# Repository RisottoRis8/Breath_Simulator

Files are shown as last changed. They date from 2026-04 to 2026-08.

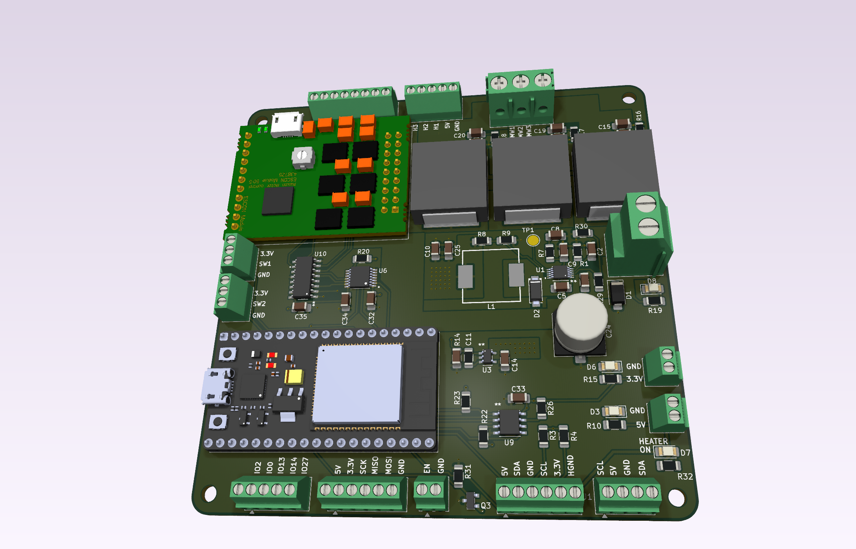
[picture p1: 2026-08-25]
hardware/documentation/others/motherboard_rev2.png

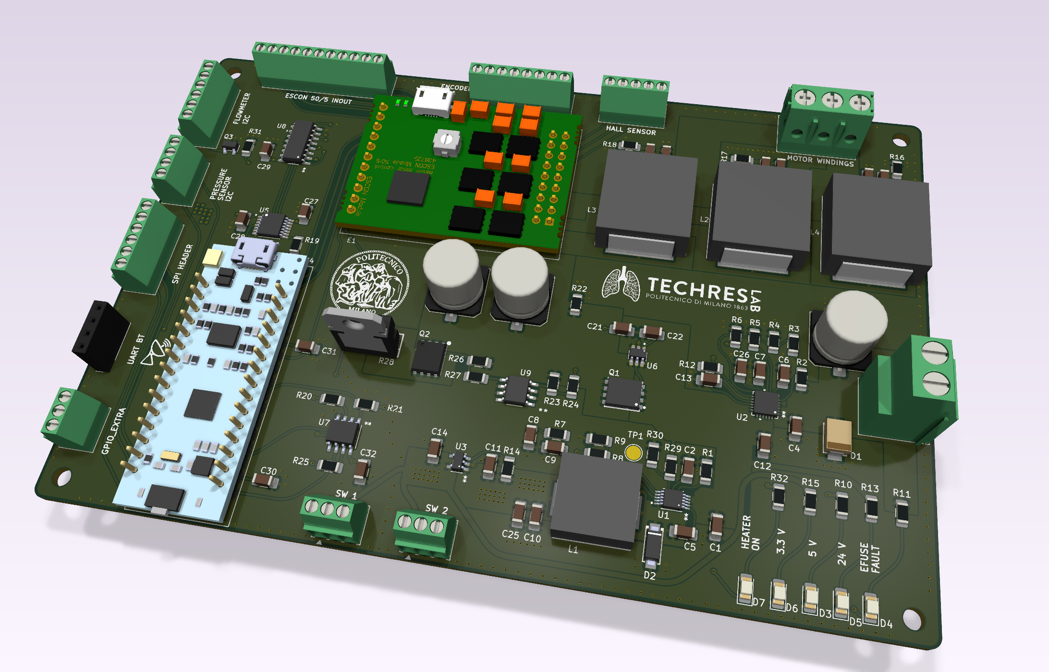
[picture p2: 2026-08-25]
hardware/documentation/others/motherboard.png

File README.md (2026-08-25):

# Syringe-Based Breathing Simulator

University biomedical engineering project developed by Gruppo Viola: a motorized syringe generates controlled air flow at its outlet. The system combines a BLDC motor with an ESCON 50/5 drive, encoder feedback, Sensirion pressure or mass-flow sensing, PID control, BLE communication and a desktop monitoring GUI.

This repository presents the final ESP32-based system together with its electronics, control software, measurement data and technical documentation. Earlier firmware, interface and hardware iterations are preserved separately as supporting development history.

## System overview

The final firmware runs on an ESP32 and coordinates:

- flow sensing through SDP810 or SFM3300 devices;
- motor control through the ESCON driver;
- incremental encoder feedback and homing signals;
- PID regulation of the generated flow;
- external SPI EEPROM storage;
- HM-10 compatible BLE telemetry and commands.

The final architecture is supported by a custom control board and a desktop BLE interface. Earlier STM32 and ESP32 bridge implementations are preserved as development iterations.

## Repository map

| Area | Contents |
| --- | --- |
| [docs](docs/) | Report, architecture notes, protocol notes and project catalog |
| [firmware](firmware/) | ESP32 and STM32 firmware area |
| [software/gui](software/gui/) | Main desktop control interface, [main_gui.py](software/gui/main_gui.py) |
| [software/tools](software/tools/) | BLE terminal, CSV visualizer and Python dependency notes |
| [hardware](hardware/) | KiCad boards, custom libraries and board documentation |
| [analysis/matlab](analysis/matlab/) | Measurement interpolation and resistance-analysis scripts |
| [data/measurements/raw](data/measurements/raw/) | Original experimental CSV measurements |
| [mechanical/renders](mechanical/renders/) | Syringe assembly render |
| [archive](archive/) | GUI prototypes and duplicate/legacy experiments |
| [docs/references/datasheets](docs/references/datasheets/) | Component reference documents |
| [archive/sensor-sdp800](archive/sensor-sdp800/) | Sensor sample-code project and documentation |

The detailed working inventory is in [docs/PROJECT_CATALOG.md](docs/PROJECT_CATALOG.md).

## Final system

- **Controller:** [firmware/esp32/main](firmware/esp32/main) coordinates sensing, encoder feedback, motor actuation, PID flow regulation, EEPROM storage and BLE communication.
- **Control interface:** [software/gui/main_gui.py](software/gui/main_gui.py) provides BLE discovery, connection management, real-time flow/position/PWM plots, operating modes, calibration controls, logging and emergency stop.
- **Electronics:** [hardware/motherboard-r2](hardware/motherboard-r2) and [hardware/pogo-adapter](hardware/pogo-adapter) contain the KiCad designs for the control board and sensor adapter. The original motherboard design is preserved as [motherboard-r1](hardware/motherboard-r1).
- **Validation data:** [data/measurements/raw](data/measurements/raw/) contains the experimental acquisitions used during characterization and analysis.

## Communication status

The final ESP32 interface uses an HM-10-compatible BLE service (`FFE0/FFE1`) and telemetry frames in the form `SNSR <flow> <encoder_position> <pwm>`. The communication details are summarized in [docs/protocol.md](docs/protocol.md).

The earlier Nordic UART bridge and STM32 variants remain available in [archive](archive/) as development iterations and are not part of the primary ESP32 control path.

## Running the Python tools

The main GUI requires Python packages including PyQt6, pyqtgraph, bleak and qasync. The BLE terminal declares its dependency in [requirements-ble.txt](software/tools/requirements-ble.txt).

The CSV visualizer is a separate Streamlit utility:

```text
streamlit run software/tools/visualizer.py
```

Its expected columns are `Timestamp_s` and `Pressione_Pa`; the raw measurements commonly use `Time_s` and `Pressure_Pa`, so they are not directly interchangeable yet.

## Firmware and hardware

The Arduino ESP32 sketch is located in [firmware/esp32/main](firmware/esp32/main) and uses the local NimBLE-Arduino library in [firmware/esp32/libraries](firmware/esp32/libraries).

KiCad source files are separated from local state, backups and manufacturing exports. The root [.gitignore](.gitignore) excludes regenerable artifacts while keeping source schematics, PCB files, custom libraries and experimental measurements available for review.

## Project documentation

- [Project catalog](docs/PROJECT_CATALOG.md)
- [Communication protocol notes](docs/protocol.md)
- [Project report](docs/report_biomed.pdf)
- [Code-flow diagram](docs/architecture/code-flow-diagram.drawio)
- [Firmware pseudocode](docs/architecture/codice.pseudo)
- [Assembly render](mechanical/renders/syringe-assembly.jpg)

## Development history

Previous ESP32 sketches, STM32 firmware, BLE bridges and GUI prototypes are preserved in [archive](archive/). They document the iterations that led to the final ESP32 architecture, while the project entrypoints above describe the system delivered by the team.

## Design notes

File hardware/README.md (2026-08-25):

# Hardware

KiCad source projects, custom libraries and board revisions will be grouped here. Generated manufacturing output and local KiCad state are excluded by the root `.gitignore`.

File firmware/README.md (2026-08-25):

# Firmware

Firmware is being separated into ESP32 and STM32 projects. The active candidate and archived prototypes will be documented after the controller and hardware revision are confirmed.

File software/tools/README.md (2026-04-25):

# BLE Terminal

A cross-platform command-line BLE terminal program that scans for BLE devices and connects to BLE UART emulators (Nordic NUS).

## Requirements

- Python 3.8+
- bleak library

## Installation

```bash
cd PythonBLECOMM
pip install -r requirements.txt
```

## Usage

```bash
python ble_terminal.py
```

### Features

1. **Scan** - Automatically scans for 5 seconds and lists all nearby BLE devices
2. **Select** - Enter the device number to connect
3. **Connect** - Connects to the selected device using Nordic UART Service (NUS)
4. **Interactive Mode** - Type messages to send, received data is displayed automatically

### Commands in Interactive Mode

- **Type and press Enter** - Send data to BLE device
- `quit` / `exit` / `q` - Disconnect and exit
- `help` - Show help

### Nordic UART Service UUIDs

- Service: `6e400001-b5a3-f393-e0a9-e50e24d4179e`
- TX (Write): `6e400002-b5a3-f393-e0a9-e50e24d4179e`
- RX (Notify): `6e400003-b5a3-f393-e0a9-e50e24d4179e`

## Platform Notes

### macOS
- May need to grant Bluetooth permissions in System Preferences
- Works with native CoreBluetooth (handled by bleak)

### Linux
- May need to install BlueZ: `sudo apt install bluez`
- May need to run with sudo or add user to bluetooth group

### Windows
- Works natively with Windows BLE API
- May need to install Bluetooth LE Enumerator from Windows Update

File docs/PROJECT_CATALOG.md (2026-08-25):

# Project catalog

This document is the repository inventory for the project presented in the root README.

## Public project areas

| Area | Current location | Target location | Status |
| --- | --- | --- | --- |
| Project documentation | `README.md`, `docs/`, `mechanical/` | `README.md`, `docs/`, `mechanical/` | Organized |
| ESP32 main firmware | `firmware/esp32/main/` | `firmware/esp32/main/` | Final system |
| ESP32 bridges and sketches | `firmware/esp32/bridges/` | `firmware/esp32/bridges/`, `archive/` | Prototype/history |
| STM32 projects | `firmware/stm32/` | `firmware/stm32/`, `archive/` | Historical implementations |
| Python GUI | `software/gui/main_gui.py` | `software/gui/` | Final ESP32 control interface |
| Python tools | `software/tools/` | `software/tools/` | Utilities |
| KiCad boards | `hardware/motherboard-r1/`, `hardware/motherboard-r2/`, `hardware/pogo-adapter/` | `hardware/` | Preserve sources |
| KiCad custom libraries | `hardware/libraries/` | `hardware/libraries/` | Required dependency |
| MATLAB analysis | `analysis/matlab/` | `analysis/matlab/` | Analysis source |
| Measurements | `data/measurements/raw/` | `data/measurements/raw/` | Experimental data |
| Datasheets and sensor examples | `docs/references/datasheets/`, `archive/sensor-sdp800/` | `docs/references/`, `archive/` | Review licenses and relevance |

## Verified technical facts

- `firmware/esp32/main/` is the final ESP32 firmware implementation.
- `software/gui/main_gui.py` is the main desktop interface for the ESP32 HM-10 service and `SNSR` telemetry.
- The repository contains both a direct ESP32 architecture and an older STM32 plus ESP32 bridge architecture.
- BLE identifiers, command syntax, telemetry frames and UART baud rates are not uniform across the repository.
- Both `hardware/motherboard-r1/` and `hardware/motherboard-r2/` contain complete KiCad source sets; `motherboard-r2` is the primary board design.
- Measurement CSV files are valuable experimental data, but their headers, units and reported scales are inconsistent.

## Classification rules

- Keep source files, custom KiCad libraries and selected experimental measurements versioned.
- Move useful prototypes and legacy implementations to `archive/` rather than deleting them.
- Ignore caches, editor state, backups, generated manufacturing output, temporary GUI logs and regenerable CAD exports.
- Present the ESP32 firmware and `main_gui.py` as the primary delivered system; keep older variants clearly separated in `archive/`.

## Notes for publication

- `motherboard-r2` is presented as the primary board design; `motherboard-r1` is retained as an earlier board revision.
- The ESP32 firmware and `main_gui.py` are the primary project entrypoints.
- Full datasheets are retained as project references; generated manufacturing output, caches and backups are ignored.
- Raw measurements are retained with their original schemas and documented as experimental data.

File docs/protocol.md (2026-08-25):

# Communication protocol notes

This document summarizes the communication path used by the final ESP32 system.

## ESP32 system

- Device name: `Polmone`
- Service: `0000FFE0-0000-1000-8000-00805F9B34FB`
- Characteristic: `0000FFE1-0000-1000-8000-00805F9B34FB`
- Telemetry frame: `SNSR <flow> <encoder_position> <pwm>`
- Serial monitor baud rate: `115200`

The main GUI sends commands through the same HM-10 characteristic and parses the `SNSR` telemetry frame. The resistance command uses the firmware syntax `R : <value>`.

## Previous bridge architecture

- Service family: Nordic UART Service
- UART baud rate in code: `57600`
- A bridge comment mentions `9600`; the code and comment must be reconciled.

## Development history

The repository also contains earlier GUI and firmware variants using Nordic UART identifiers, different device names, comma-separated telemetry and other baud rates. They are retained under [archive](../archive/) as development history and are not part of the primary ESP32 control path.

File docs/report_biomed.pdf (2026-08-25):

Politecnico di Milano

Electronic Technologies and Biosensors Laboratory

# Breathing Simulator: Final Project Report

## Violet Group

Professor:
Prof. Chiara Veneroni

Project Supervisor:
Matteo Mentasti

Group Members
Francesco Amaglio
Martina Artuffo
Alessandro Carbone
Simone Ghini
Andrea Penserini
Cristian Petramale

Academic Year 2025/2026

August 25, 2026

# Contents

1 Introduction | 3
2 PCB Design | 5
3 3D Modeling and Assembly | 12
4 Firmware | 16

5 GUI | 26
6 Main Challenges and Solutions | 32
7 Testing Phase | 35
8 Conclusions & Future Work | 36

# 1 Introduction

## 1.1 Background

The controlled reproduction of respiratory airflow patterns plays an important role in the development and bench testing of sensors, monitoring systems, and other biomedical devices designed to measure or interact with respiration. A breathing simulator provides a repeatable and controllable experimental platform through which different respiratory conditions can be reproduced without requiring the direct involvement of a human subject.

During spontaneous breathing, airflow alternates between inspiration and expiration as a consequence of cyclic changes in thoracic volume and pressure. Although quiet breathing can be approximated by a smooth periodic waveform, physiological respiratory signals are not perfectly sinusoidal and may present variations in amplitude, duration, the relative duration and timing of inspiration and expiration, and cycle-to-cycle regularity. Therefore, a breathing simulator intended for biomedical testing should be able to generate both simple and repeatable reference profiles, such as steady and sinusoidal flows, and more realistic respiratory patterns obtained from in vivo recordings.

The system developed within Project Violet is an adult breathing simulator based on the controlled displacement of a syringe plunger. The syringe acts as a variable-volume chamber, while its piston is driven by a brushless motor through a mechanical transmission system. The resulting piston displacement generates airflow at the syringe outlet, which can be controlled to reproduce different respiratory profiles. An incremental optical encoder monitors the actuator motion, while flow and differential-pressure sensors measure the pneumatic output of the system. A microcontroller coordinates actuator control, sensor acquisition, and the exchange of commands and measurement data with external software.

The project started from a pre-existing mechanical structure that had already been partially assembled. However, the initial prototype was not yet suitable for operation as a complete, reliable, and integrated breathing simulator. Several 3D-printed components presented structural, dimensional, or compatibility limitations and therefore required redesign and manufacturing. Moreover, the integration of the selected brushless motor and optical encoder required the development of dedicated mechanical adapters and supports. New components were consequently designed for the motor, encoder, limit switches, syringe, and electronic board, with the aim of improving mechanical stability, component alignment, and overall system integration.

Beyond the mechanical redesign, the project required the development of a custom printed circuit board, embedded firmware, and computer software. The firmware was developed to manage the actuator interfaces, monitor the mechanical motion through the encoder, perform timed sensor acquisition, and communicate with the external control application. The computer software provided the functions required to configure the system, select its operating modes, monitor the acquired signals, and support testing and debugging. These elements were combined into a single functional mechatronic platform integrating mechanical actuation, electronic control, sensing, and data communication.

## 1.2 Objectives

The main objective of the project was to design and develop a functional adult breathing simulator capable of generating steady and sinusoidal airflow profiles, as well as reproducing respiratory patterns previously recorded in vivo. The simulator was intended to provide controlled and repeatable pneumatic outputs that could be used for the development and evaluation of respiratory sensors and monitoring systems.

From a mechanical perspective, the project aimed to adapt and improve the available prototype by redesigning and manufacturing the required 3D-printed supports and adapters. Particular attention was given to the correct positioning and alignment of the syringe, transmission components, brushless motor, incremental encoder, limit switches, and electronic hardware.

From an electronic perspective, the objective was to design and fabricate a custom printed circuit board capable of integrating the microcontroller, motor driver, encoder, flow and pressure sensors, communication interfaces, and the required power and signal connections.

The embedded firmware was developed to manage actuator commands, monitor the system motion through the encoder, acquire the pneumatic sensor signals at defined time intervals, and exchange commands and measurement data with a laptop. In parallel, computer software was implemented to configure the operating parameters, control the simulator, visualize the acquired signals, and support the execution of the different respiratory modes.

The overall objective was therefore to integrate the mechanical, electronic, firmware, and software subsystems into a complete and operational prototype, and to verify its ability to generate the required respiratory airflow patterns under controlled and repeatable conditions.

# 2 PCB Design

## 2.1 System Architecture

The main purpose of the electronic system is to acquire data from the sensors, process them on the main MCU, and then control the motor’s velocity. The architecture is functionally divided into data acquisition/processing and in a dedicated power management section.

### 2.1.1 Logic and Data Acquisition

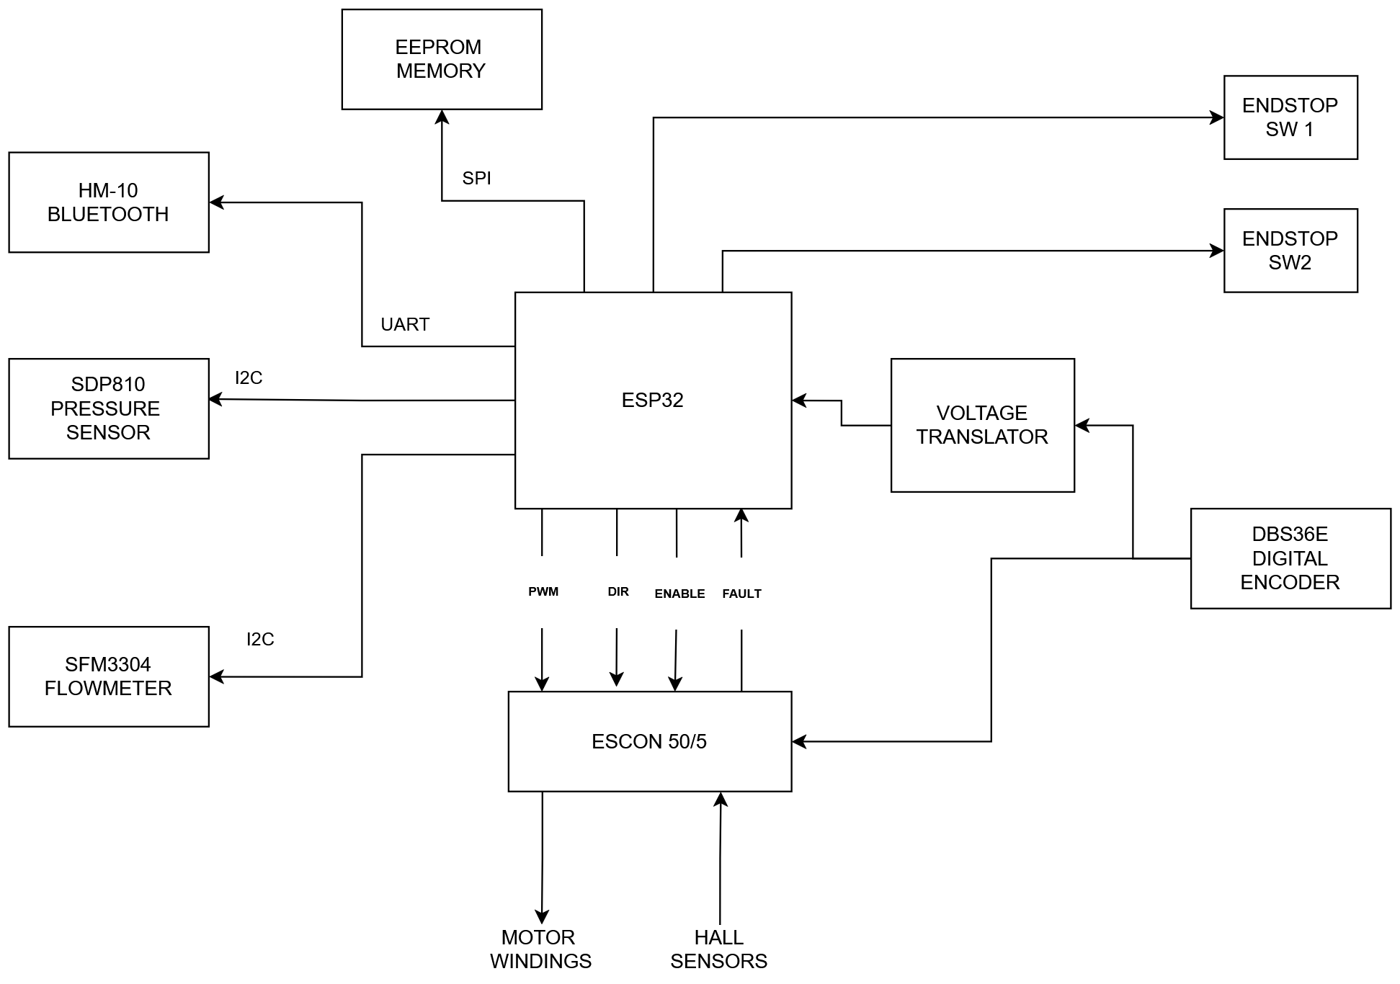
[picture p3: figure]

Figure 2.1: Logic architecture of the system

As shown in the system diagram (2.1), multiple peripherals interface with the ESP32 to monitor and control every aspect of the system:

- Sensirion SDP810 Pressure Sensor

Operating as the primary sensor in the control loop, this device senses the pressure difference generated by a custom pneumotachograph at the syringe output, estimating the output flow. It communicates with the ESP32 via an I2C bus

- Sensirion SFM3304 Digital Flowmeter

A secondary commercial flowmeter used to directly measure the output flow. This device is essential to calibrate the primary data source and shares the same I2C line. To ensure reliable operation in highly humid environments, an integrated anti-condensation heater can be triggered by the MCU.

- DBS36E Digital Encoder

Although not strictly required for the main feedback, a digital encoder tracks the position of the syringe. These data are used internally by the motor driver for positional feedback, and are used by the MCU to calculate software safety limits. A voltage translator is interposed between the encoder and the ESP32 to shift logic levels to standard 3.3V.

- Hall Sensors

The motor has built-in hall effect sensors that are used by ESCON to correctly drive the windings.

- Endstop Switches

Placed at the physical boundaries of the lead screw, two hardware switches complement the encoder to guarantee safety and to perform startup position recovery.

- EEPROM Memory

A dedicated non-volatile memory is included on the board to store permanent system parameters, such as PID gains, calibration curves, and software limits. This peripheral interfaces with ESP32 via a dedicated SPI bus.

- HM10 Bluetooth Module

The communication between Microcontroller and PC is handled via Bluetooth by an HM10 module. The device uses a UART peripheral to exchange data.

### 2.1.2 Motor Actuation

Motor control is handled by the ESCON 50/5, a commercial driver for DC brushless motors capable of delivering up to 5A of continuous current and 10A of peak current, providing enough torque to reach the target output flows. The driver is controlled directly by the ESP32 with three logical signals: PWM (to set speed), DIR ( to set cw or ccw rotation direction) and ENABLE ( to activate motor rotation). Additionally, a FAULT feedback line monitors possible motor related errors.

### 2.1.3 Power Management

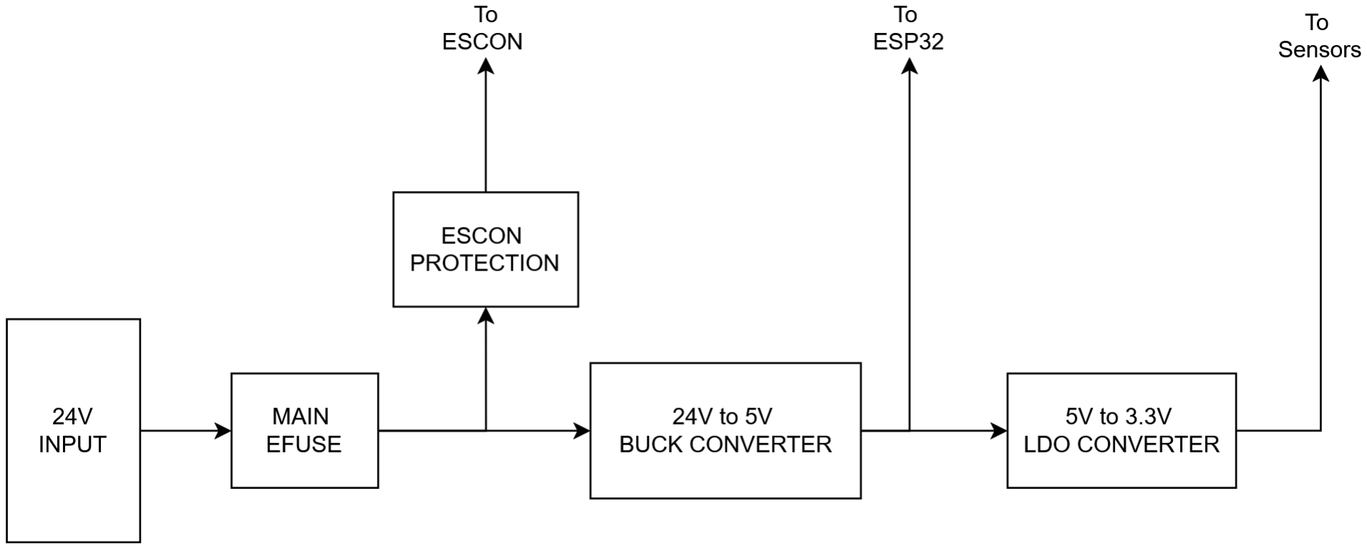
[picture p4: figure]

Figure 2.2: Power tree of the system

The system power tree is crucial for maintaining stability, given the relevant power requirements for motor actuation.

Because of the motor’s operating voltage requirements, the system is powered by an external AC-DC converter supplying 24V. This input is safeguarded by an eFuse, which protects both the PCB and the external supply from potential overcurrent and overvoltage issues.

From this protected 24V line, power is delivered across the system:

- Motor Supply

The 24V line is routed to the ESCON driver. To prevent reverse current problems, a protection circuit has been designed to decouple the supply from the driver power section.

- Logic Supply

The system features a dual voltage logic architecture. A buck converter steps down the main 24V to a 5V rail, which primarily powers the ESP32 board and the logic part of the ESCON driver. Sequentially, an LDO regulator generates a 3.3V rail that mainly powers the sensors and peripherals such as the EEPROM memory.

## 2.2 Schematic Design

Schematics documents are designed to meet clarity when read, and to represent the block scheme of the system architecture. The main sections are: MCU, Power supply, ESCON 50/5, Connectors.

### 2.2.1 Power Section

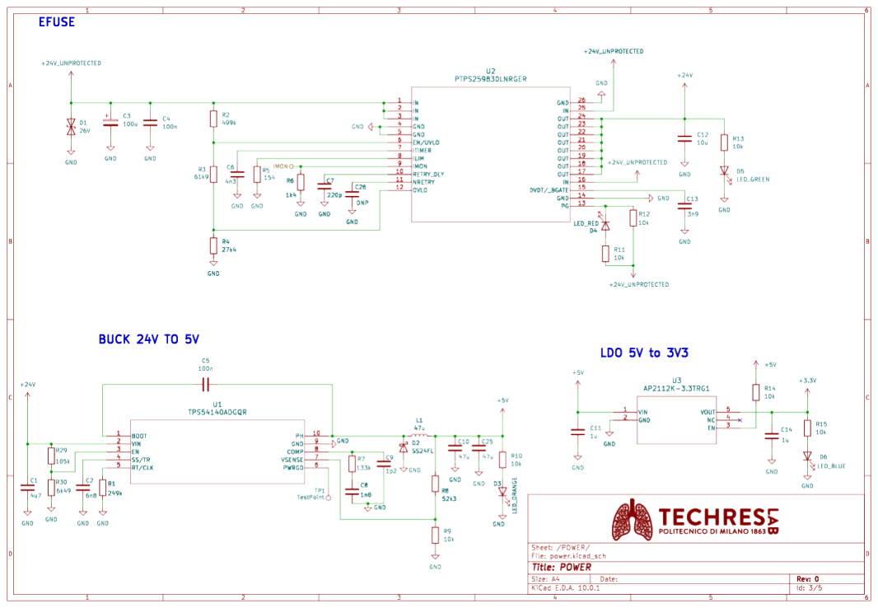
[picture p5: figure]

Figure 2.3: Power schematic sheet

The upper section of the schematic page (2.3) is occupied by the Efuse design. The chip used (TI TPS259830LNRGER) is sized to bring up to 10A of current , and to accept up to 26V in input. Status led have been added both on the protected 24V line and on a fault pin of the chip.

Lower section shows the components involved in the main voltage references generation: the left one is the buck converter (TI TPS54140ADGQR) and is designed to deliver up to 1.5A of stable current at 5V. The right chip is instead the LDO converter ( Diodes AP2112K-3.3) that can deliver 500mA at 3.3V.

### 2.2.2 ESCON 50/5 and Protection

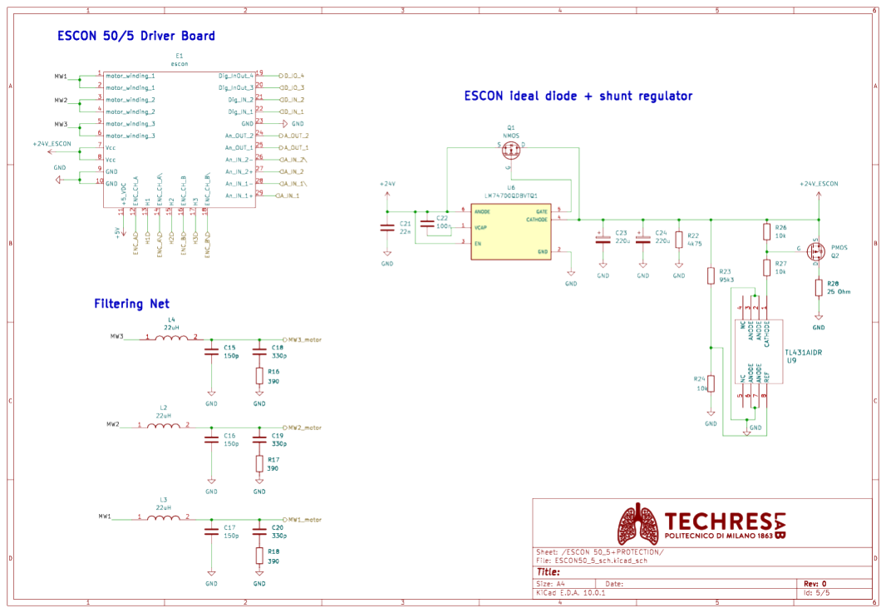
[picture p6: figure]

Figure 2.4: ESCON schematic sheet

To make the ESCON module work, the design features filtering networks for every motor winding, and a custom designed circuit to prevent reverse current effects due to the inductive behaviour of the motor. Focusing on the shunt circuit, the left chip ( TI LM74700QDBVTQ1) drives a mosfet to act as a reverse biased diode, with zero voltage drop. This prevents the current from flowing to the rest of the 24V rail. Another component needed for the protection is the shunt regulator ( TI TL431), which discharges the return current on a 25 ohm resistor when voltage increases over a threshold of 26V.

### 2.2.3 MCU and EEPROM

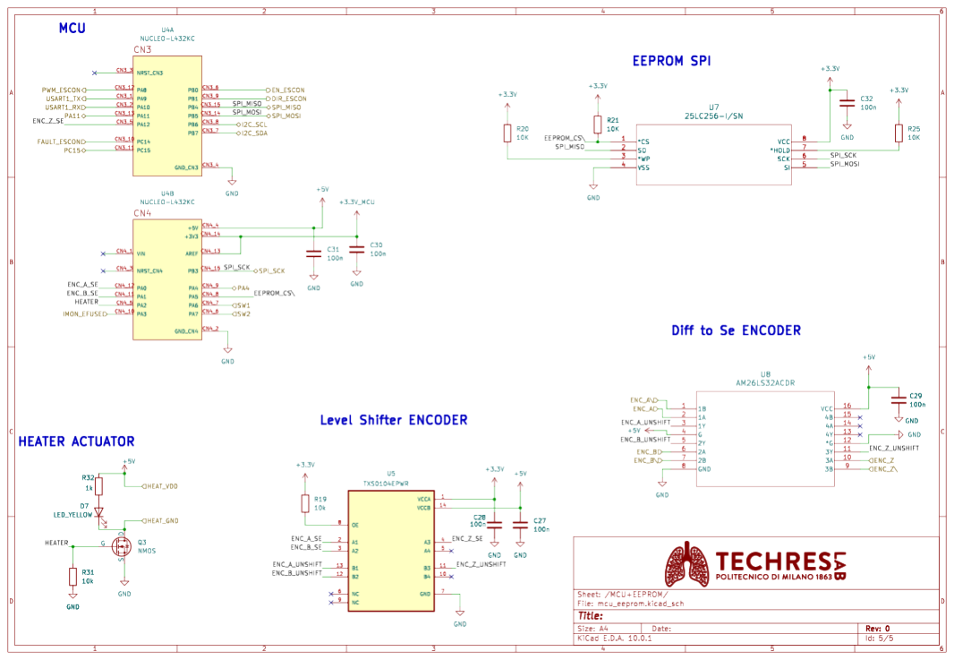
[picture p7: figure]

Figure 2.5: Microcontroller schematic sheet

The most important schematic part is the one regarding Microcontroller board, EEPROM and voltage translation for the encoder data. Here we should note that, in the original design, the MCU selected for calculations was an STM32 board; as will be described in the issues section, the chip has been later switched to an ESP32.

The EEPROM chip (Microchip 25LC256-I/SN) is directly connected on the MCU and features a minimal design, with only some strapping resistors and decoupling capacitors.

The data from encoder have a 2-step translation: a first device (TI AM26LS32ACDR) performs the conversion from differential to single-ended signals while the second device (TI TXS0104EPWR) shifts the logic levels from 5V of the sensor to 3.3V of the MCU.

Another important feature integrated in the project is the presence of a MOSFET switch, controlled by the Microcontroller, that activates the anti-condensation heater of the SFM3304 sensor.

### 2.2.4 Connectors

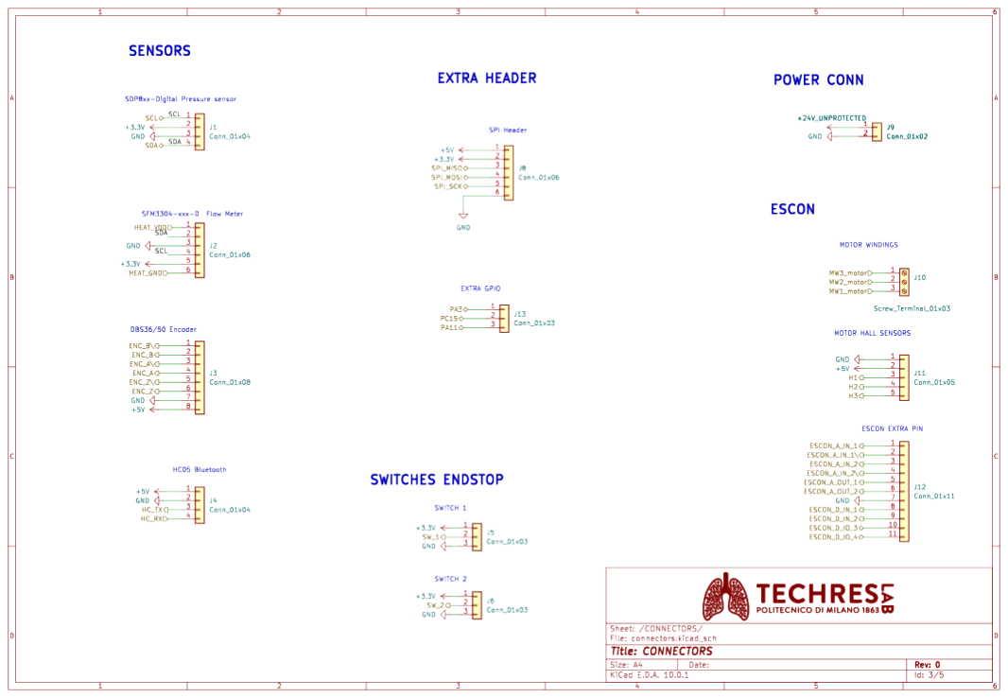
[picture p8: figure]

Figure 2.6: Connectors schematic sheet

The connector section groups all the inputs and outputs of the board in a single sheet. Connections are divided in logical blocks: Sensors, switches endstops, extra headers, ESCON and motor connections, power input.

## 2.3 PCB Layout

### 2.3.1 Stackup and Manufacturing Choices

The physical layout has been engineered to meet different requirements on manufacturing and usability of the device.

The board features 4 layers, divided as:

- Top layer: Fast signals and smd components
- Ground Plane : A solid ground plane to guarantee signal integrity for the data
- Power plane: A layer divided in different areas that bring the right supply to chips and

modules

- Bottom layer: Slower signals and other connections

To reduce manufacturing and assembly costs, all the smd components are placed only on the top layer of the board. This also ensures a better mechanical mount of the board in the system, due to no components underneath.

Another important aspect is the clear separation between the logic part on the left and the right section on the right: the use of switching regulators for the supply and the field effects generated from the motor could be a problem for logical signal, so as a best practice they are kept as distant as possible.

### 2.3.2 Connector Placement

First of all, the connectors position ensure a fast and efficient cable management of all the peripherals. Those are divided in sections: on the upper part are located the connectors for motor windings, hall sensors, encoder and a debug port for ESCON pins. All the sensors for flow are in the right part of the board, together with the Bluetooth module and with an extra SPI header. Connector for main power input is placed in the right edge of the board.

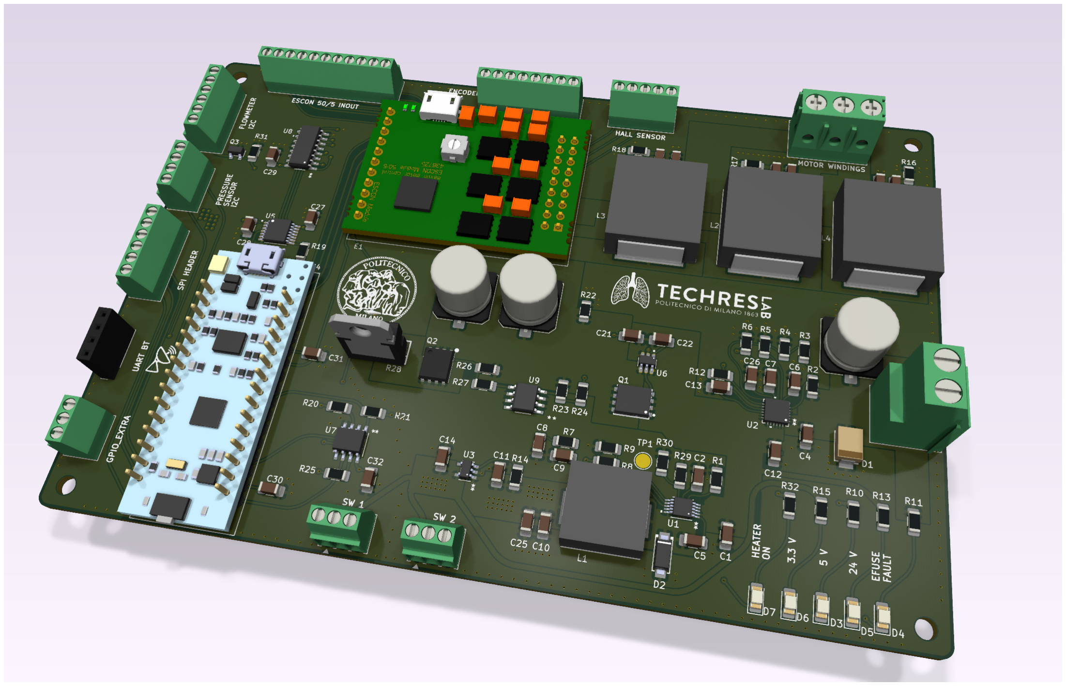
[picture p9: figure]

Figure 2.7: PCB Layout at version 1

# 3 3D Modeling and Assembly

The next challenge was to integrate all the components into a single system. The syringe, the encoder, the motor, the Sensirion flowmeter sensor, the sliding bar and the support to convert the rotary motion of the motor to the compression and retraction of the syringe were already available. However, the physical supports were old or outdated (for instance, by changing the motor to a brushless one, its support had to be changed). After taking the measurements, the Autodesk Fusion software was used to design the basic components, which were later printed in resin.

## 3.1 CAD Models

### 3.1.1 Switch Supports

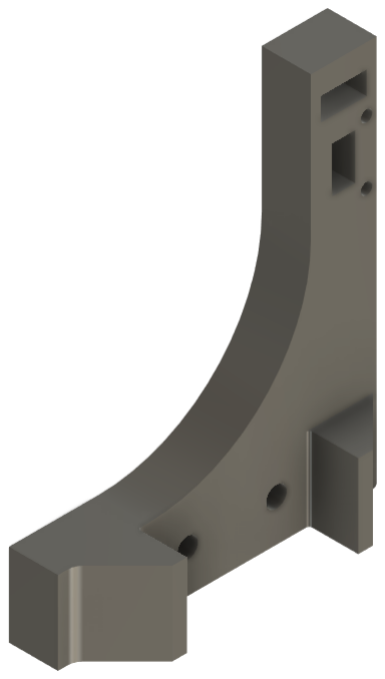
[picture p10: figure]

Figure 3.1: Switch support

These components were created to hold the microswitches in order to fix them in place with two screws and use them to stop the motion of the motor when activated for safety precautions. They are fixed on the sides of the main support through screws and they mark the START and END positions. The smooth curved shapes are to avoid fragility issues. Even though it is unlikely because of how it was coded, the motor can apply a high amount of force, so to avoid stability issues they do not pivot on the screw thanks to the two hooks.

### 3.1.2 Syringe Supports

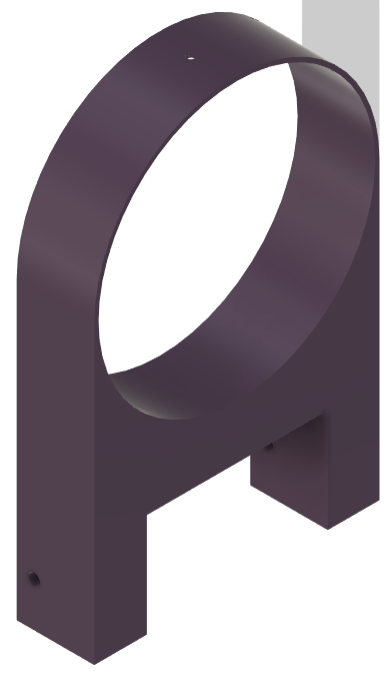
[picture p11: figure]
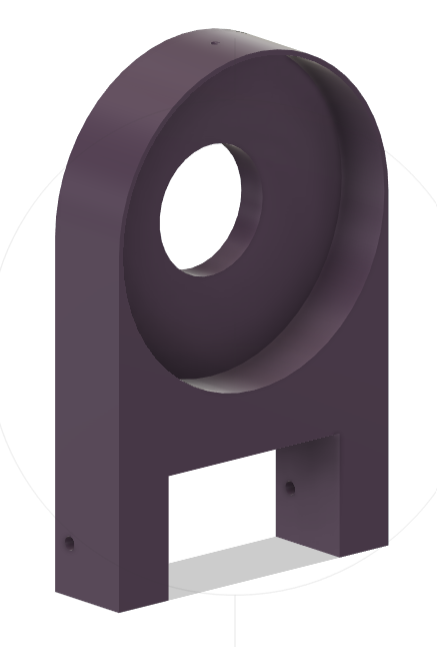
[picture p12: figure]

Figure 3.2: Syringe support

The syringe is supported by one component at the base and another one near the plunger. The second one (on the right) was printed in PLA because of time constraints related to resin printing. The main support instead has to withstand high forces because of the continuous pumping of the syringe. To avoid air leakage, tape was used between it and the syringe, but this led to issues related to the force required by the motor during the aspiration phase. Therefore, several holes were drilled to ease the motion.

### 3.1.3 Motor Support

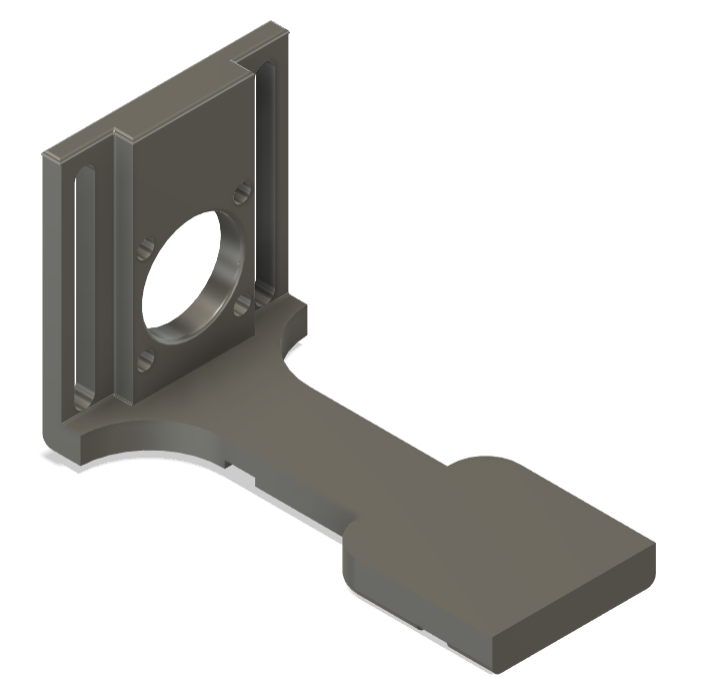
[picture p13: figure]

Figure 3.3: Motor support

The brushless motor is connected to the main screw, the one used to convert the motion into pumping, thanks to a 5–8 mm shaft coupling. The motor is positioned on top of the printed support, which is fixed to the main support with screws.

Figure 3.4: Shaft adapter

### 3.1.4 Encoder Support

The encoder is situated right behind the syringe support and connected to the main screw through a 5–8 mm shaft coupling. To improve stability, tape was used.

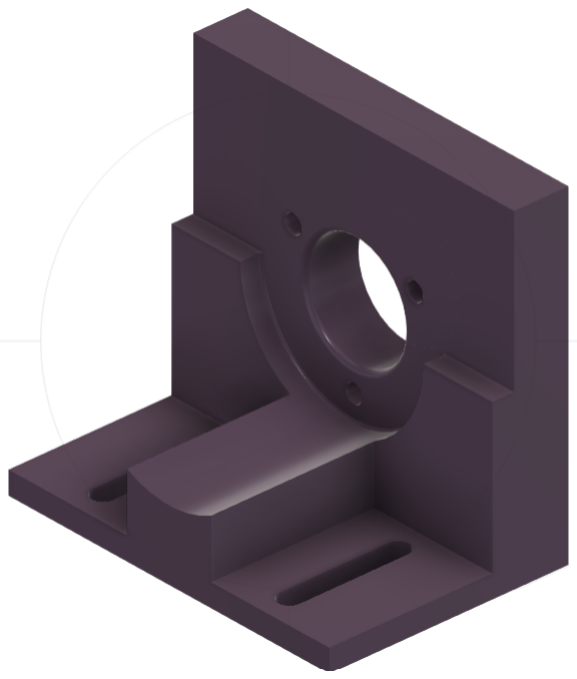
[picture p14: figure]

Figure 3.5: Encoder support

### 3.1.5 PCB Support

The main electronic control is situated behind the main support, on top of the PLA-printed backing. The PCB is fixed with two screws and the wires hang freely to the main components of the electronic board.

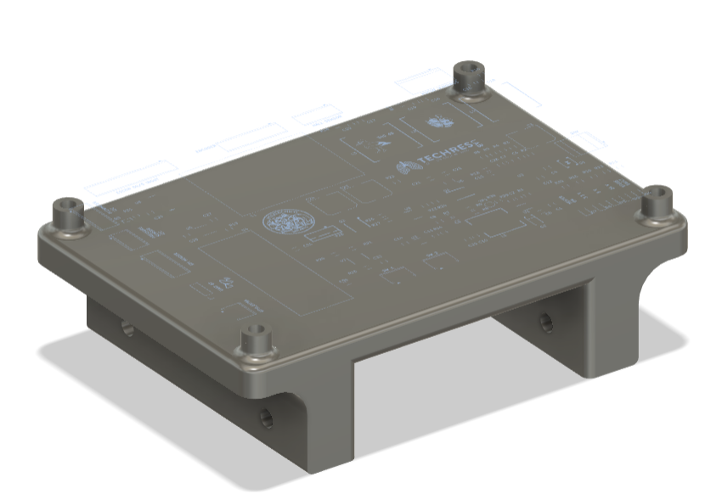
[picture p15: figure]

Figure 3.6: PCB Support

### 3.1.6 SFM3304 Adapter

The digital Sensirion flowmeter has pinouts that have to be adapted to the board to convert the sensor output into an electrically compatible signal. To this scope, a physical converter was implemented which uses the elastic shape adaptation of pogo pins to take the signal. The converter is attached to the top of the flowmeter and fixed with a latch mechanism.

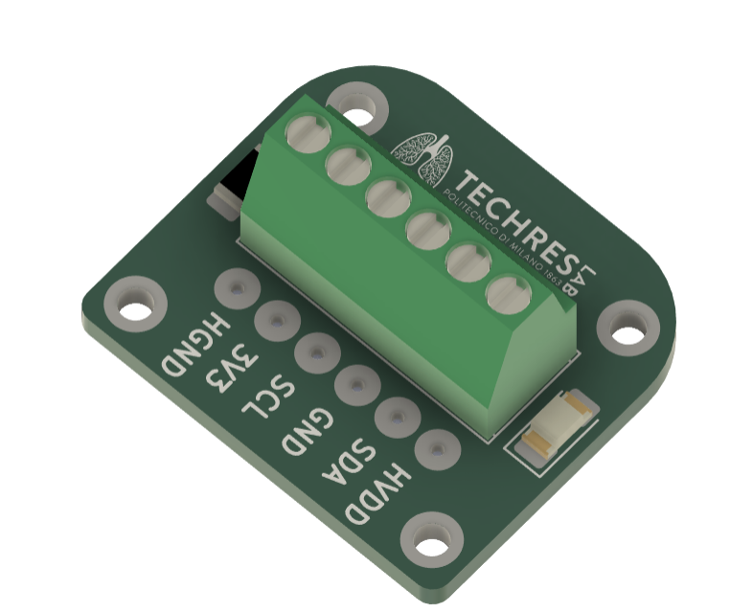
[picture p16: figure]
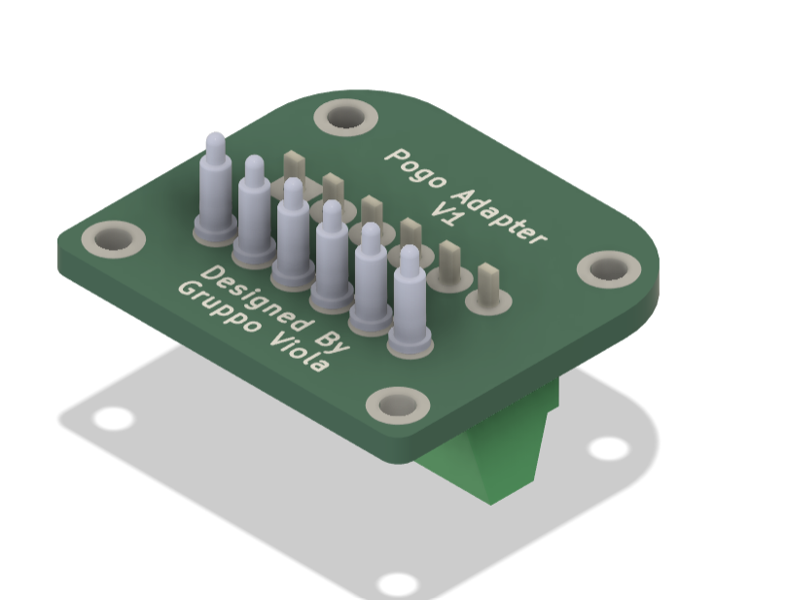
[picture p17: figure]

Figure 3.7: SFM3304 Adapter

### 3.1.7 Pneumotachograph

For feedback analysis another flowmeter is used in the project and it was designed from scratch and printed in resin. Its main features are:

- Long V-shaped mouth to adapt to the hole of the syringe.
- Two laminators of the same shape as the main resistive load (61 octagons of 0.75 mm).
- Smooth flow channel connections to resolve fragility issues.

Figure 3.8: Pneumotachograph

# 4 Firmware

## 4.1 Architecture overview

The architecture of our project is based on an ESP32 microcontroller, programmed to interface with all system peripherals. The firmware structure essentially relies on a time-driven loop, where a timer interrupt is triggered at 200 Hz. This sets a flag that is polled within the main loop to execute the critical section of the system. This approach minimizes the execution time within the Interrupt Service Routine (ISR) and mitigates potential race conditions.

Within the main loop, a Finite State Machine (FSM) orchestrates all system operations. The various states are defined in the enumeration “Modalita” and will be detailed in the following chapters.

A context wrapper, named “RespirationState”, precisely encapsulates the specific respiratory phase simulated by the device. This ensures a highly modular codebase, facilitating the seamless addition or removal of features in future iterations.

Furthermore, the system handles synchronous and asynchronous events independently. Specifically, hardware interrupts are utilized to detect external events. This enables the integration of microswitches to identify when the system reaches its mechanical limit stops.

Also, the code is very modular: Every I/O function features an abstraction function, allowing a user to easily replace them in case they need to implement the device with different sensors or actuators.

## 4.2 Memory Organization and Data Structures

The primary objective of this code section is to maximize structural organization and readability. To achieve this, we implemented various structures and enumerations:

Enum “Modalita”

1 | enum Modalita { // IL CODICE RIPRODUCE UNA MACCHINA A STATI
2 | MODE_LINEAR = 0 ,
3 | MODE_SINUSOIDAL = 1 ,
4 | MODE_CALIBRATION = 2 ,
5 | MODE_PUSH = 3 ,
6 | MODE_HOME = 4 ,
7 | MODE_IDLE = 5 ,
8 | MODE_CUSTOM_FLOW = 6 , | // NUOVO : riproduzione profilo flusso custom
9 | MODE_DEBUG_SWING = 520 ,
10 | MODE_DEBUG = 1000 ,
11 | MODE_SELF_TEST = 9999
12 | };

This serves as the state lexicon for our Finite State Machine (FSM), defining all possible operational states:

- MODE IDLE: The motor is disabled, and the system awaits a command.
- MODE LINEAR: Generates a setpoint for constant flow, calculated as the ratio between the

target volume and the half-period. A PID controller is utilized to track the target.

- MODE SINUSOIDAL: Generates a variable flow setpoint approximating a sinusoidal curve,

thereby simulating a physiological breathing pattern. This is constrained by the maximum volume limit, with active PID control.

- MODE CUSTOM FLOW: Interpolates an array of instantaneous flow setpoints pre-loaded into

memory, enabling the reproduction of customized curves via PID control.

- MODE CALIBRATION: Executes motion in discrete fractional increments to verify volumetric

accuracy.

- MODE PUSH: Executes manual movement at a constant speed in a specified direction, op-

erating in an open-loop configuration.

- MODE HOME: Executes a slow, constant movement towards the home (rest) position.
- MODE DEBUG SWING: Mechanical stress-testing mode. The motor operates at a constant

PWM duty cycle in a single direction until software limits are triggered.

- MODE DEBUG: System diagnostic and debugging mode.
- MODE SELF TEST: Initialization routine designed to calibrate and store the end-stop posi-

tion values.

These state definitions ensure mutually exclusive execution.

struct ”ControllerConfig”

1 | struct ControllerConfig { // STRUTTURE DATI CHE INCLUDONO PARAMETRI DI CONTROLLO
| , STATO E VALORI LETTI DI VARI SETTORI DEL CODICE
2 | float kp = 0.05 f ;
3 | float ki = 0.005 f ;
4 | float kd = 0.0 f ;
5 | float kff = 0.10 f ;
6 | float kff_diff [2] = { 0.0 f , 0.0 f };
7 | float kff_quad = 0.02 f ;
8 | float resistance = 1.0 f ;
9 | float syringe_volume_L = 1.0 f ;
10 | } config ;

Contains all PID tuning parameters and system mechanical constants. This structure facilitates the seamless uploading and saving of calibration profiles to the EEPROM.

Struct “RespirationState”

1 struct RespirationState {

2 | Modalita mode = MODE_IDLE ;
3 | TipoSensore sensor = NESSUNO ;
4 | float target_volume_L = 0.0 f ;
5 | float semiperiod_sec = 0.0 f ;
6 | float accumulated_vol_L = 0.0 f ;
7 | float current_flow = 0.0 f ;
8 | float pressure = 0.0 f ;
9 | bool is_inspiration = true ;
10 | unsigned long phase_start_ms = 0;

11
12 | int tick = 0;
13 | float integral = 0.0 f;
14 | float prev_error = 0.0 f ;
15 | float last_output_error = 0.0 f ;
16 | unsigned long prev_pid_time = 0;
17 | } breath ;

Serving as the context wrapper, this structure represents the real-time state of the system throughout its operation, acting as a dynamic snapshot. It encapsulates:

- Target kinematics (e.g., volume and time).
- Sensor data (e.g., instantaneous flow, pressure, and computed accumulated volume).
- Current PID variables and motor status.

This architecture significantly enhances state observability and allows for a safe, comprehensive reset of the system context when necessary.

Struct “MotorState”

1 | struct MotorState {
2 | float current_pwm_norm = 0.0 f ;
3 | int current_pwm_raw = 0;
4 | bool direction = false ;
5 | bool enabled = false ;
6 | bool flag_invert_req = false ;
7 | bool flag_near_end = false ;
8 | bool flag_too_near = false ;

9
10 | float swing_pwm = 0.0 f ;
11 | bool swing_dir = true ;
12 | } motor ;

Contains the current PWM duty cycle applied to the motor, along with a set of flags dedicated to handling boundary conditions when the carriage approaches critical dynamic limits. Its primary purpose is to manage motor pin configurations, providing a hardware abstraction layer for the system.

Struct “HardwareVolatiles”

1 | struct HardwareVolatiles {
2 | volatile bool sample_200hz = false ;
3 | volatile bool microswitch_clash = false ;
4 | volatile long encoder_pos = 0;
5 | volatile long max_encoder_steps = 0;
6 | volatile unsigned long last_irq_ms = 0;
7 | } hw ;

Groups all volatile variables within the system, including timer flags, microswitch interrupt flags, and encoder step counts. These are strictly declared as volatile to force the compiler to fetch their current values directly from RAM upon every access, as they can be modified asynchronously by hardware interrupts.

Struct ”CustomFlowState”

1 | struct CustomFlowState {
2 | float flow_wp [ CFLOW_MAX_WAYPOINTS ]; | // [L/s] | ( positivo = inspirazione ,
| negativo = espirazione )
3 | uint32_t time_wp [ CFLOW_MAX_WAYPOINTS ]; | // [ms] | dalla partenza
4 | uint16_t num_wp = 0;
5 | uint16_t current_wp = 0; | // indice del waypoint corrente ( precedente )
6 | unsigned long start_ms = 0; | // millis () al via
7 | bool armed = false ;
8 | } cflow ;

The custom flow mode necessitates specific optimization due to its high computational complexity. This structure encapsulates all the data required to map a custom breathing pattern. Specifically, it contains arrays storing all pre-calculated waypoints and their corresponding timestamps.

## 4.3 Interrupt Service Routines

The real-time architecture of our system requires a strict decoupling of synchronous (time-driven) and asynchronous (event-driven) events. Consequently, we implemented an interrupt architecture designed to handle and categorize all incoming events. It is crucial to note that the Interrupt Service Routines (ISRs) refrain from executing computationally intensive algorithms; instead, they are strictly limited to setting boolean flags. This defers the actual data processing to the main loop, thereby preventing bottleneck conditions and ensuring overall firmware stability.

### 4.3.1 Synchronous events

All these events are governed by a hardware timer configured to generate an interrupt every 5 ms (200 Hz).

1 | timer200Hz = timerBegin (1000000) ; | | // Risoluzione a 1 MHz (1
| tick = 1 us)

2 | timerAttachInterrupt ( timer200Hz , & onTimer200Hz ) ; | // Aggancio della ISR
3 | timerAlarm ( timer200Hz , 5000 , true , 0) ; | // Allarme sincrono ogni
5000 us (5 ms -> 200 Hz) con ricarico automatico ( true )

4
5 | void IRAM_ATTR onTimer200Hz () {
6 | hw . sample_200hz = true ;
7 | }

The routines executed within this temporal constraint include:

- Sensor reading: The I2C bus is polled at exactly 200 Hz to acquire uniformly sampled

data.

1 | float valoreletto = NAN ;
2 | breath . pressure = NAN ;
| 3
4 | if ( breath . sensor == SDP810 ) {
5 | valoreletto = leggi_SDP810 () ;
6 | if (! isnan ( valoreletto ) ) {
7 | breath . pressure = valoreletto ;
8 | breath . current_flow = valoreletto / config . resistance ;
9 | }
10 | } else if ( breath . sensor == SFM3300 ) {
11 | valoreletto = leggi_SFM3300 () ;
12 | if (! isnan ( valoreletto ) ) breath . current_flow = valoreletto ;
13 | } else {
14 | breath . current_flow = flow_from_encoder ;
15 | valoreletto = breath . current_flow ;
16 | }
- Setpoint generation and PID: In custom flow mode, the system tracks the elapsed time

from the start of the pattern. Based on the specified period and the adjacent waypoints, it computes the instantaneous target value via interpolation. Furthermore, it evaluates the terms required for closed-loop control. Notably, our controller extends the traditional Proportional-Integral-Derivative (PID) algorithm by incorporating a feed-forward term. This predictive component actively compensates for the pressure drops within the pneumatic system, modeled according to Poiseuille’s law.

- Telemetry: This block includes a prescaler counter. Every ten timer ticks, it sets a

transmission flag to schedule Bluetooth communication. This downsampling guarantees data transmission at exactly 20 Hz, which is well within the bandwidth limitations of the HM-10 BLE module.

1 | // BLE Telemetry Downsampling (200 Hz to 20 Hz)
2 | static int contatore_ble = 0;
3 | contatore_ble ++;
| 4
5 | if ( contatore_ble >= 10) { // Condition met every 10 timer ticks (50 ms)
6 | contatore_ble = 0;
7 | char msg_buf [64];
| 8
9 | // Format the data payload
10 | snprintf ( msg_buf , sizeof ( msg_buf ) , " SNSR %.3 f %ld %d %.3f %.3f \r\n",

11 | breath . current_flow , hw . encoder_pos , motor . current_pwm_raw ,
12 | breath . last_output_error , breath . pressure ) ;

13
14 | // Asynchronous transmission over BLE characteristic
15 | if ( deviceConnected && pTxCharacteristic != nullptr ) {
16 | pTxCharacteristic - > setValue (( uint8_t *) msg_buf , strlen ( msg_buf ) ) ;
17 | pTxCharacteristic - > notify () ;
18 | }
19 | }

### 4.3.2 Asynchronous events

The primary asynchronous events in this architecture are triggered by the microswitches—acting as the fundamental hardware safety mechanism of the machine—and the two channels of the rotary encoder:

- End-stops: Two limit switches are positioned at the extremities of the lead screw to be

physically actuated by the carriage. Without this intervention, the carriage would collide with the mechanical boundaries, potentially inducing a motor stall condition, leading to excessive current draw and thermal overload.

1 | void IRAM_ATTR onEmergencyStop () {
2 | unsigned long tempo_attuale = millis () ;

3
4 | // Software Debounce : Ignora i trigger successivi al primo per 3000 ms
5 | if ( tempo_attuale - hw . last_irq_ms > 3000 &&
6 | ( digitalRead ( PIN_LIMIT_SW1 ) == LOW || digitalRead ( PIN_LIMIT_SW2 ) ==
| LOW ) ) {

7
8 | hw . microswitch_clash = true ; // Flag asincrono letto dal loop
| principale
9 | hw . last_irq_ms = tempo_attuale ;
10 | }
11 | }
- Encoder channels: The encoder generates pulses continuously as the motor drives the

carriage. Every rising or falling edge triggers a hardware interrupt, allowing the system to accurately track and update the absolute position of the carriage in real-time. We don’t use the Z channel as it provides less resolution.The first peripheral inputs necessitate the implementation of a digital debounce filter to prevent false triggering and interrupt storms. Meanwhile, the encoder uses a look-up table to decode the quadrature.

1 | void IRAM_ATTR onEncoderISR () {
2 | // Quadrature Decoding Lookup Table : mappa le transizioni di stato in
| incrementi (+1 , -1 , o 0)
3 | static int8_t lookup_table [] = { 0 , -1 , 1 , 0 , 1 , 0 , 0 , -1 , -1 , 0 , 0 , 1 ,
| 0 , 1 , -1 , 0 };
4 | static uint8_t enc_val = 0;

5
6 | // Bare - Metal Register Access : Lettura simultanea dei pin GPIO a
| bassissimo livello
7 | uint32_t reg = REG_READ ( GPIO_IN1_REG ) ;

8 | uint8_t a = ( reg >> 2) & 1; // Estrae lo stato del PIN_ENC_A ( GPIO 34)
9 | uint8_t b = ( reg >> 3) & 1; // Estrae lo stato del PIN_ENC_B ( GPIO 35)

10
11 // Costruzione dell ’indice binario e aggiornamento della variabile

volatile
12 | enc_val = enc_val << 2;
13 | enc_val = enc_val | (( a << 1) | b ) ;
14 | hw . encoder_pos += lookup_table [ enc_val & 0 b1111 ];
15 | }

## 4.4 Bluetooth communication

The system requires bidirectional PC communication for supervisory control, telemetry logging, and parameter configuration. To achieve this, we integrated an HM-10 module, which acts as a wireless UART bridge over Bluetooth Low Energy (BLE). The communication interface operates in an event-driven idle state, utilizing interrupt callbacks triggered only upon the reception of incoming data payloads.

1 | class MyCallbacks : public BLECharacteristicCallbacks {
2 | void onWrite ( BLECharacteristic * pCharacteristic ) override {
3 | String rxValue = pCharacteristic - > getValue () ;
4 | if ( rxValue . length () > 0) {
5 | Serial . print ( rxValue ) ;
6 | for (int i = 0; i < (int ) rxValue . length () ; i ++) {
7 | char c = rxValue [ i ];
8 | if ( c == ’\n’ || c == ’\r’) {
9 | if ( ble_rx_index > 0) {
10 | parser () ;
11 | ble_rx_index = 0;
12 | ble_rx_buffer [0] = ’\0 ’;
13 | }
14 | } else {
15 | if ( ble_rx_index < sizeof ( ble_rx_buffer ) - 1) {
16 | ble_rx_buffer [ ble_rx_index ++] = c ;
17 | ble_rx_buffer [ ble_rx_index ] = ’\0 ’;
18 | }
19 | }
20 | }
21 | }
22 | }
23 | };

### 4.4.1 Data Reception

Implementing a blocking wait to receive and interpret an entire string sequentially would severely compromise the real-time performance. Such an approach would induce control loop jitter, halting system execution and unnecessarily increasing mechanical stress on the motor. To mitigate this, incoming data bytes are asynchronously appended to a static buffer. CPU execution is diverted only briefly to copy the payload into RAM, ensuring the motor control loop remains undisturbed. This non-blocking buffering process continues iteratively until a predetermined termination character is detected.

### 4.4.2 Command Parser

Upon detection of the termination character, a dedicated parser() routine is invoked to decode the buffered payload and execute the corresponding command.

The parser supports the following instruction set:

- Mode 0 <volume> <time>: Activates linear flow mode.
- Mode 1 <volume> <time>: Activates sinusoidal flow mode.
- CFLOW <flow1> <time1> <flow2> <time2> ...: Activates custom interpolated flow mode.
- Mode 7 <direction> <speed>: Activates manual open-loop carriage displacement.
- Mode 4 <direction>: Initiates the homing sequence.
- STOP: Immediately halts all actuation.

Additionally, it accepts configuration commands for controller tuning:

- PID <Kp> <Ki> <Kd>: Overwrites the proportional, integral, and derivative gains.
- KFF <value>: Sets the linear feed-forward base gain.
- KFFDiff <direction0> <direction1>:Configures the asymmetric feed-forward offset.
- KFFQuad <value>: Sets the quadratic feed-forward coefficient.
- R <value>: Defines the pneumatic/hydraulic resistance.
- Volume <value>: Defines the total volumetric capacity of the system.

Furthermore, the interface supports calibration and non-volatile memory operations:

- Mode 9999: Triggers the self-calibration routine to map hardware limit switch boundaries.
- Mode 2 <volume> <time> <steps>: Initiates resistance curve calibration, streaming out-

put data in .csv format for subsequent plotting.

- FWV:<string>: Commits the current controller configuration to EEPROM for persistent

storage.

### 4.4.3 Data Transmission

1 | void send_BLE ( const String & messaggio ) {
2 | if ( deviceConnected && pTxCharacteristic != nullptr ) {
3 | String payload = messaggio + "\r\n";
4 | pTxCharacteristic - > setValue ( payload . c_str () ) ;
5 | pTxCharacteristic - > notify () ;
6 | }
7 | }

As previously mentioned, to accommodate the HM-10 module’s bandwidth limitations, telemetry data transmission is downsampled to 20 Hz. This strategy is essential to prevent transmit buffer overflow and client-side saturation.

### 4.4.4 GUI synchronization

The microcontroller acts as the single source of truth for the system’s configuration. Therefore, upon establishing a connection with the host PC, the firmware initiates a brief delay before transmitting the persistent PID parameters stored in the EEPROM to the client. This initialization sequence ensures full synchronization between the host interface and the current hardware state.

## 4.5 PID Architecture

As the system is strongly non linear, we need a PID that’s able to track the flow even in challenging scenarios. Due to that, the PID features, apart from the classic PID parameters, a second degree, asymmetric, feed forward polynomial to improve speed, accuracy and reduce ringing

1 | {
2 | float error = setpoint - flow_abs ;

3
4 | int dir_idx = breath . is_inspiration ? 0 : 1;
5 | float base_ff = config . kff + config . kff_diff [ dir_idx ];
6 | float ff_term = ( setpoint * base_ff ) + ( config . kff_quad * setpoint *
| setpoint ) ;

7
8 | float raw_derivative = ( error - breath . prev_error ) / dt ;
9 | static float filtered_derivative = 0.0 f ;
10 | filtered_derivative = (0.2 f * raw_derivative ) + (0.8 f *
| filtered_derivative ) ;

11
12 | float p_term = config . kp * error ;
13 | float d_term = config . kd * filtered_derivative ;
14 | float tentative_output = ff_term + p_term + ( config . ki * breath .
| integral ) + d_term ;

15
16 | const float OUT_MAX = MOTOR_MAX_PWM_NORM ;
17 | const float OUT_MIN = 0.0 f ;

18
19 | bool hit_upper = ( tentative_output >= OUT_MAX ) ;
20 | bool hit_lower = ( tentative_output <= OUT_MIN ) ;

21
22 | if (! hit_upper && ! hit_lower ) {
23 | breath . integral += error * dt ;
24 | } else if ( hit_upper && error < 0.0 f ) {
25 | breath . integral += error * dt ;
26 | } else if ( hit_lower && error > 0.0 f ) {
27 | breath . integral += error * dt ;
28 | }

29
30 | float final_output = ff_term + p_term + ( config . ki * breath . integral ) +
| d_term ;
31 | if ( final_output > OUT_MAX ) final_output = OUT_MAX ;
32 | if ( final_output < OUT_MIN ) final_output = OUT_MIN ;

33
34 | breath . last_output_error = final_output ;

35 | breath . prev_error = error ;

36
37 | setMotor ( final_output , ! breath . is_inspiration , true ) ;
38 | }
39 | }

# 5 GUI

## 5.1 Main goal

To govern the system, we developed a dedicated host software application designed to establish bidirectional communication. The core component is a Graphical User Interface (GUI) tailored for transmitting commands, monitoring system telemetry, and rendering real-time data visualizations.

The application is built upon the PyQt6 framework, leveraging the Qt toolkit to ensure a highly optimized and professional-grade user experience. Furthermore, the bleak library is integrated to manage Bluetooth Low Energy (BLE) connectivity, guaranteeing cross-platform compatibility across various operating systems.

Finally, data plotting is handled via pyqtgraph. This library was specifically selected over matplotlib due to its superior optimization and rendering performance in high-refresh-rate, real-time applications.

## 5.2 Communication management

PyQt6 operates on a synchronous event loop, meaning that any blocking I/O or computationally expensive operation will render the Graphical User Interface (GUI) unresponsive. Conversely, the ’bleak’ Bluetooth library is natively asynchronous, creating an inherent architectural incompatibility out of the box.

1 | if __name__ == " __main__ ":
2 | app | = QApplication ( sys . argv )

3
4 | # 1. Creazione dell ’event loop ibrido tramite qasync
5 | loop = qasync . QEventLoop ( app )
6 | asyncio . set_event_loop ( loop )

7
8 | window = HM10App ()
9 | window . show ()
10 | QTimer . singleShot (0 , window . btn_scan . click )

11
12 | # 2. Avvio del loop concorrente ( gestisce sia UI che BLE)
13 | with loop :
14 | | loop . run_forever ()

To resolve this, we integrated the qasync library. This module seamlessly merges the standard Python asyncio event loop with the PyQt6 QEventLoop, enabling time-consuming BLE routines to execute concurrently. Consequently, the application can manage asynchronous network operations within a single-threaded architecture while maintaining full GUI responsiveness.

1 | @asyncSlot ()
2 | async def connect_device ( self ) :
3 | # ... logica asincrona non bloccante per connettersi al BLE ...
4 | self . client = BleakClient ( address )
5 | await self . client . connect ()
6 | # ...

Regarding data reception on the client side, incoming payloads are similarly buffered. The data fragments are iteratively appended to an array until a termination character is detected. This mechanism ensures the complete and accurate reconstruction of the message, guaranteeing data integrity before the payload is forwarded to the command parser.

1 | def _rx_handler ( self , sender , data : bytes ) :
2 | self . rx_buffer += data
3 | while b"\n" in self . rx_buffer :
4 | line , self . rx_buffer = self . rx_buffer . split ( b"\n", 1)
5 | clean = line . replace ( b"\r", b"") . decode ("utf -8", errors =" ignore ") .
| strip ()
6 | asyncio . get_event_loop () . call_soon_threadsafe ( self . _process_line ,
| clean )

## 5.3 State synchronization and input validation

Upon establishing a connection with the host PC, the microcontroller immediately transmits the PID parameters stored in the EEPROM alongside the firmware version, encapsulated within a unique data string. This procedure ensures the full synchronization of the host’s real-time system state with the device’s persistent configuration.

The parse and populate rom function receives this payload, parses the string, and populates the corresponding internal variables with the extracted values.

1 | def _parse_and_populate_rom ( self , line : str ) :
2 | clean = line [4:]. strip ()
3 | tokens = clean . split ()

4
5 | if len ( tokens ) < 17 or tokens [1] != " PIDSDP " or tokens [9] != " PIDENC ":
6 | self . txt_debug . append ( f"[ROM ERR ] Formato EEPROM incompatibile : {
| line }")
7 | return

8
9 | try :
10 | self . rom_fw . setText ( tokens [0])
11 | keys = [" kff", " kffd0 ", " kffd1 ", " kff_quad ", "kp", "ki", "kd"]

12
13 | for i , k in enumerate ( keys ) :
14 | self . rom_sdp [ k ]. setText ( tokens [2 + i ])
15 | self . rom_enc [ k ]. setText ( tokens [10 + i ])

16
17 | self . txt_debug . append ("[ ROM] Parametri EEPROM uC caricati nella GUI
| con successo .")
18 | except Exception as e :
19 | self . txt_debug . append ( f"[ ROM ERR] Errore popolamento GUI: {e}")

Furthermore, the GUI serves as a robust validation layer, permitting the upload of custom flow waypoints only if the dataset strictly adheres to the following constraints:

- A minimum of two waypoints must be defined.
- The initial timestamp must be strictly equal to zero.
- The timestamp values must increase monotonically.

If any of these conditions are violated, the application rejects the input and generates an error prompt. Following a successful validation, the system transmits the command payload previously detailed in Chapter 4.4.

## 5.4 Plot Rendering

This rendering process represents a potential performance bottleneck for the GUI; direct, synchronous updates could induce severe latency and frame drops due to the bandwidth constraints of the communication link. To mitigate this, we decoupled the data acquisition and rendering tasks:

Initially, incoming telemetry data is asynchronously appended to a buffer array upon arrival.

1 | t = time . time () - self . start_time
2 | self . t_data . append ( t )
3 | self . flow_data . append ( flow )
4 | self . pos_data . append ( pos )
5 | self . pwm_data . append ( pwm )
6 | self . pid_err_data . append ( pid_out )
7 | self . pressure_data . append ( pressure )
8 | self . _plot_dirty = True

Concurrently, a dedicated software timer triggers every 33 ms (achieving an effective refresh rate of approximately 30 Hz) to poll for buffer updates. If new data is detected, the plotting routines are executed. This architectural decoupling ensures optimal rendering fluidity and prevents user interface blocking.

Finally, the visualized data is displayed using a 10-second rolling window to provide a continuous temporal overview of the system’s dynamics.

1 | def _refresh_plots ( self ) :
2 | if not self . _plot_dirty or not self . t_data :

3 | return
4 | self . _plot_dirty = False

5
6 | t = list ( self . t_data )

7
8 | if not self . is_calibrating :
9 | cutoff = t [ -1] - ROLLING_WINDOW_S
10 | idx | = next (( i for i , v in enumerate ( t ) if v >= cutoff ) , 0)
11 | t | = t [ idx :]
12 | flow = list ( self . flow_data ) [ idx :]
13 | pos | = list ( self . pos_data ) [ idx :]
14 | pwm | = list ( self . pwm_data ) [ idx :]
15 | pid | = list ( self . pid_err_data ) [ idx :]
16 | pre | = list ( self . pressure_data ) [ idx :]
17 | else :
18 | flow = list ( self . flow_data )
19 | pos | = list ( self . pos_data )
20 | pwm | = list ( self . pwm_data )
21 | pid | = list ( self . pid_err_data )
22 | pre | = list ( self . pressure_data )

23
24 | self . line_flow . setData (t , flow )
25 | self . line_pressure . setData (t , pre )
26 | self . line_pos . setData (t , pos )
27 | self . line_pwm . setData (t , pwm )
28 | self . line_pid_err . setData (t , pid )

## 5.5 Data logging abstraction

Since the ESP32 lacks an onboard filesystem (such as an SD card module) to store large datasets, the PC application acts as the primary data logger during the MODE CALIBRATION sequence.

### 5.5.1 File I/O Abstraction

To handle data recording systematically, a dedicated CalibrationLogger class was implemented.

1 | class CalibrationLogger :
2 | def __init__ ( self , ref_volume : float , resistance : float ) :
3 | self . ref_volume | = ref_volume
4 | self . resistance | = resistance

5
6 | ts | = int ( time . time () )
7 | self . path | = f" calibration_ {ts }. csv "
8 | self . _file = open ( self . path , mode ="w", newline ="", encoding ="utf -8")
9 | self . _w | = csv . writer ( self . _file )

10
11 | self . _w . writerow (["# Reference Volume (L)", ref_volume ])
12 | self . _w . writerow (["# Resistance ", | resistance ])
13 | self . _w . writerow (["# Started ", | time . strftime ("%Y -%m -% dT%H
:%M:%S") ])

14 | self . _w . writerow ([])
15 | self . _file . flush ()

16
17 | self . current_step | : int | None = None
18 | self . step_start_time | : float | None = None
19 | self . _header_written | = False

20
21 | def begin_step ( self , step_number : int) :
22 | self . current_step | = step_number
23 | self . step_start_time = time . time ()

24
25 | self . _w . writerow ([])
26 | self . _w . writerow ([ f"# --- STEP { step_number } ---"])

27
28 | if not self . _header_written :
29 | self . _w . writerow ([" Step ", " Timestamp_s ", " RelTime_s ", " Pressure_Pa "
| ])
30 | self . _header_written = True

31
32 | self . _file . flush ()

33
34 | def log_sample ( self , pressure : float ) :
35 | if self . current_step is None or self . step_start_time is None :
36 | return
37 | abs_t = time . time ()
38 | rel_t = abs_t - self . step_start_time
39 | self . _w . writerow ([
40 | self . current_step ,
41 | f"{ abs_t :.4f}",
42 | f"{ rel_t :.4f}",
43 | f"{ pressure :.5f}",
44 | ])

45
46 | def end_step ( self ) :
47 | self . _file . flush ()

48
49 | def close ( self ) -> str:
50 | self . _file . flush ()
51 | self . _file . close ()
52 | return self . path

Upon initialization, it generates a unique .csv file appended with a UNIX timestamp to prevent the accidental overwriting of previous tests. It immediately writes a metadata header containing the user-defined Reference Volume and pneumatic Resistance, ensuring each dataset is selfcontained for future offline analysis.

### 5.5.2 Event-Driven Synchronization

The logging process is not continuous but strictly synchronized with the microcontroller’s mechanical steps via string token handshakes. When the firmware completes a movement and stabilizes, it transmits a READY token followed by the step index. The GUI intercepts this event, resets a local relative timer, and begins logging the high-resolution pressure samples. Conversely, a TURN token signals the end of the mechanical step, halting the data acquisition

for that block.

### 5.5.3 Data Integrity

To safeguard against potential data loss caused by unexpected BLE disconnections or software crashes, the logger explicitly calls the flush() method at key transitions. This forces the host operating system to immediately write the memory buffers to the physical storage drive, ensuring that all acquired calibration data is safely preserved.

# 6 Main Challenges and Solutions

Throughout the realization of the project, among the main sections (such as the code, the 3D design and printing, the PCB board, and the assembly part), some problems were encountered. These issues were challenging and required problem-solving and analysis to find a solution.

## 6.1 Software Issues

### 6.1.1 Outdated Bluetooth Module

In 2026, the drivers for the HC05 module used for Bluetooth communication stopped working correctly. After debugging, the best solution was to change the module. At first an ESP32 microcontroller was used only for communication purposes; then the updated HM10 communication device solved the problem.

### 6.1.2 UART Communication Complications

The STM microcontroller uses UART to communicate with the ST-Link and the GUI. It took a while to understand that the protocol stopping working meant the microcontroller board had failed. At first it was replaced with another one, but to make the code more compact and, especially, to simplify connectivity with the other devices, the STM was then substituted with an ESP32.

## 6.2 Wrong Measurements for CAD Models

After realizing that the printed components were offset, too big or simply did not fit, it was better not to print them again because of time constraints. The reason the components were crooked was due to the limitations of the resin printer and inaccurate measurements. So it was decided to try to fix them through drilling and filing: sandpaper was used to make what could not fit slimmer, while a drill was used to make holes for the screws since they were offset. After the testing phase, the solution was to design them again with more accurate measurements, this time with extra features:

- A 0.1 mm margin every 10 mm; this helped the components fit better and almost perfectly.
- Smoother angles; as discussed for the Switch Support, not having sharp edges avoided

fragility issues.

It is to be noticed the presence of a perfectly fixed screw between the encoder and syringe support: this is to avoid the latter moving too much because of the forces applied by the motor.

## 6.3 PCB Issues and Fixes

### 6.3.1 Main PCB Issues

During the use and testing phase of the original PCB design, some errors and critical issues arose:

- Change of MCU

As previously mentioned in PCB section, during the development the Microcontroller board has been updated from an STM32 to an ESP32 board, with the consequent need to adapt pinout for the module.

- ESCON Protection circuit

The ESCON reverse current protection circuit delivered some critical issues in the first instance, by sending the Efuse in protection mode at startup. This prevented the whole board from working and needed a bypass of the circuit.

- I2C pull-up resistors

By a misunderstanding in the design phase, the I2C line was left without pull-up resistors, making the communication with sensors impossible.

### 6.3.2 Second Review and Design Improvements

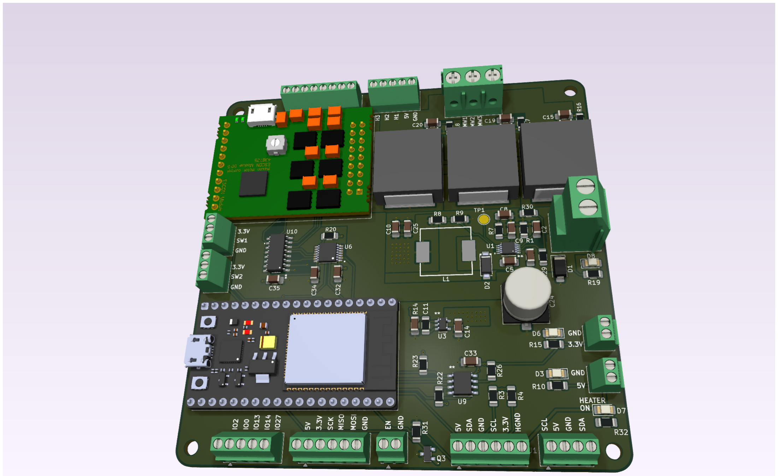
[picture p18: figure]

Figure 6.1: Second PCB Revision

Due to the multiple issues related to the original design, a second version of the PCB has been created. Here are the main changes applied to the project:

- Simplified Power Supply

During testing, the protection circuitry was found to be unnecessarily complex for the intended application. Therefore, to reduce cost and simplify the design, both the eFuse and the malfunctioning ESCON protection circuit were removed from the second PCB revision.

- ESP32 Integration

As described before, the new board features the pinout for ESP32 module, leaving behind the legacy STM32 compatibility.

- Compact design

Due to the smaller Bill of Materials, also the size of the PCB has been reduced to meet both a better usability and a lower production cost.

- Better Silkscreen

To improve the user experience, all the pins of connectors now have their signal printed on the top silkscreen ( in the older version this feature was present only on the bottom side, and due to mechanical mount this was not easily reachable).

- Other minor fixes

Some other minor issues have been addressed and corrected, such as the missing I2C pullup resistor and some wrong connected pins.

# 7 Testing Phase

During the final phase of the project, calibration and functional tests were performed to evaluate the operation of the integrated system and identify the remaining mechanical and control limitations.

## 7.1 Calibrations

The first test focused on the calibration of the resin-printed pneumotachograph using a 3 L reference syringe. By displacing a known volume over a controlled time interval, the corresponding reference flow rate was estimated. The differential-pressure measurements were then associated with the reference flow values to determine the pressure–flow characteristic and the effective pneumatic resistance of the device.

Initially, the calibration was performed manually by observing and analysing the acquired curves. The procedure was subsequently automated through dedicated software, which stored the measurements in CSV files and processed them to estimate the pressure–flow relationship and the corresponding resistance curve. The experimental results showed a nonlinear dependence of the apparent pneumatic resistance on the pressure difference, with the estimated resistance increasing as the pressure difference increased.

## 7.2 System Validation

Following manufacturing and assembly, some of the 3D-printed components required manual adjustments, including filing and drilling, to ensure proper alignment and integration. During the initial motor tests, the mechanical loads damaged some of the less robust supports. These components were subsequently redesigned and manufactured with increased structural strength. Further tests confirmed the improved mechanical stability of the revised solution.

Final functional tests were performed on the implemented linear, sinusoidal, and custom-flow modes using the PID-based control strategy. During the initial trials, the actuator experienced increased mechanical resistance in the aspiration phase. This issue was reduced by modifying the syringe support to improve air circulation behind the syringe. Following this correction, the system successfully executed the implemented airflow-generation modes during the performed tests. However, the tests were primarily functional, and a complete quantitative comparison between the target and measured profiles remains necessary.

# 8 Conclusions & Future Work

## 8.1 Conclusions

Project Violet led to the development of a functional adult breathing simulator based on the motor-driven displacement of a syringe plunger. Starting from a partially assembled and outdated prototype, the mechanical, electronic, firmware, and software subsystems were progressively redesigned and integrated into a single mechatronic platform.

From a mechanical perspective, new supports and adapters were designed and manufactured for the brushless motor, encoder, syringe, limit switches, electronic board, and pneumatic sensors. Several initial components presented dimensional inaccuracies or insufficient mechanical strength and therefore required manual correction or complete redesign. The final modifications improved component alignment and structural stability, allowing the system to withstand the forces generated during repeated syringe actuation.

The electronic system was developed to integrate the motor driver, flow and pressure sensors, encoder, end-stop switches, communication interfaces, and power-management circuitry. During development, the original STM32-based architecture was replaced by an ESP32-based solution to simplify peripheral integration and communication. The first PCB revision revealed several critical issues, including missing I²C pull-up resistors, incompatibility with the new mi-

crocontroller, and problems related to the ESCON protection circuitry. These limitations were temporarily mitigated through corrective modifications and hardware bypasses applied to the first PCB, enabling functional testing of the prototype. Based on the issues identified during this phase, a second, simplified PCB revision was subsequently designed, although it was not fabricated or experimentally validated within the project timeframe.

The firmware was organized around a time-driven architecture and a finite-state machine supporting multiple operating, calibration, safety, and diagnostic modes. It coordinated sensor acquisition, setpoint generation, PID-based motor control, position monitoring, and telemetry through synchronous and asynchronous events.

The pneumatic measurement system included a commercial flowmeter and a custom resin-printed pneumotachograph. The latter was calibrated by applying known volume displacements and relating the measured differential pressure to the corresponding airflow. The calibration procedure was progressively automated, allowing the acquired data to be stored and processed to estimate the pressure-flow relationship of the device.

Final functional tests showed that the simulator was able to execute the implemented airflow waveforms. Initial difficulties during the syringe aspiration phase were reduced by modifying the syringe support to improve air circulation. Following this correction and the reinforcement of the most mechanically stressed components, the system operated successfully during the performed tests.

Overall, the main project objective was achieved: the mechanical, electronic, firmware, and software components were integrated into an operational prototype capable of executing the implemented respiratory airflow-generation modes. Nevertheless, the tests performed mainly demonstrated the functional feasibility of the system. A more extensive quantitative characterization is still required to determine its accuracy, repeatability, dynamic performance, and operating limits.

## 8.2 Future Work

Future development should first focus on a complete experimental validation of the simulator. The generated flow, pressure, and volume profiles should be compared with reference measurements over the entire intended operating range. Repeated trials should be performed for each operating mode to quantify accuracy, repeatability, settling time, waveform-tracking error, and cycle-to-cycle variability.

The calibration of the custom pneumotachograph should also be extended to a wider range of positive and negative flows. Its measurements should be systematically compared with those of the commercial Sensirion flowmeter, and the resulting calibration relationship should be stored in non-volatile memory and automatically applied by the firmware.

Further work is required to optimize the PID controller. The controller parameters should be tuned and validated for different respiratory amplitudes, frequencies, mechanical loads, and directions of motion. Particular attention should be given to the aspiration phase, in which friction, pressure losses, and mechanical resistance produced greater actuation difficulties. The predictive contribution included in the control strategy should also be quantitatively evaluated to determine its effective improvement in waveform tracking.

From a mechanical perspective, temporary solutions such as tape, manually drilled holes, and adjusted printed components should be replaced with redesigned parts manufactured using appropriate tolerances and more resistant materials. The syringe and encoder supports could be further reinforced, while the pneumatic path should be redesigned to reduce leakage, dead volume, unwanted resistance, and flow disturbances. Long-duration endurance tests would also be useful to evaluate wear of the transmission system, couplings, syringe, and printed components.

The second PCB revision should be fabricated and experimentally validated. Particular attention should be given to power integrity, signal integrity, I²C communication, encoder level

translation, motor-driver interfacing, electromagnetic interference, and thermal behaviour. The revised board should also be tested under motor start-up, direction reversal, emergency-stop, and fault conditions.

Additional safety improvements could include redundant position monitoring, a fully validated and mandatory start-up homing and self-test procedure, improved management of hardware and software limits, pressure and flow thresholds, communication timeouts, and automatic motor shutdown under abnormal operating conditions.

Finally, the external software could be expanded with improved real-time visualization, automatic test execution, calibration tools, data logging, and quantitative comparison between desired and measured waveforms. A larger library of physiological and pathological respiratory patterns could also be introduced, allowing the simulator to reproduce more realistic in vivo signals and increasing its usefulness for the development and evaluation of respiratory monitoring devices.

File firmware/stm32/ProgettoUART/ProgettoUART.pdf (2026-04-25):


22/04/2026

ProgettoUART Project
Configuration Report

## 1. Description

### 1.1. Project

Project Name | ProgettoUART
Board Name | custom
Generated with: | STM32CubeMX 6.15.0
Date | 04/22/2026

### 1.2. MCU

MCU Series | STM32L4
MCU Line | STM32L4x2
MCU name | STM32L432KCUx
MCU Package | UFQFPN32
MCU Pin number | 32

### 1.3. Core(s) information

Core(s) | Arm Cortex-M4

## 2. Pinout Configuration

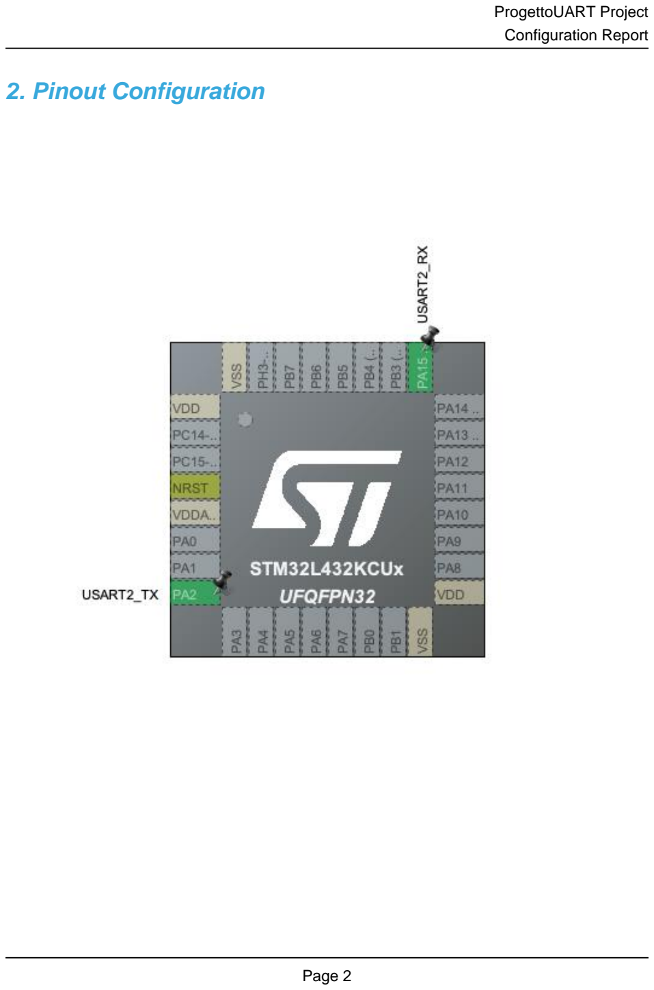
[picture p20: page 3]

## 3. Pins Configuration

Pin Number UFQFPN32 | Pin Name (function after reset) | Pin Type | Alternate Function(s) | Label
1 | VDD | Power
4 | NRST | Reset
5 | VDDA/VREF+ | Power
8 | PA2 | I/O | USART2_TX
16 | VSS | Power
17 | VDD | Power
25 | PA15 (JTDI) | I/O | USART2_RX
32 | VSS | Power

## 4. Clock Tree Configuration

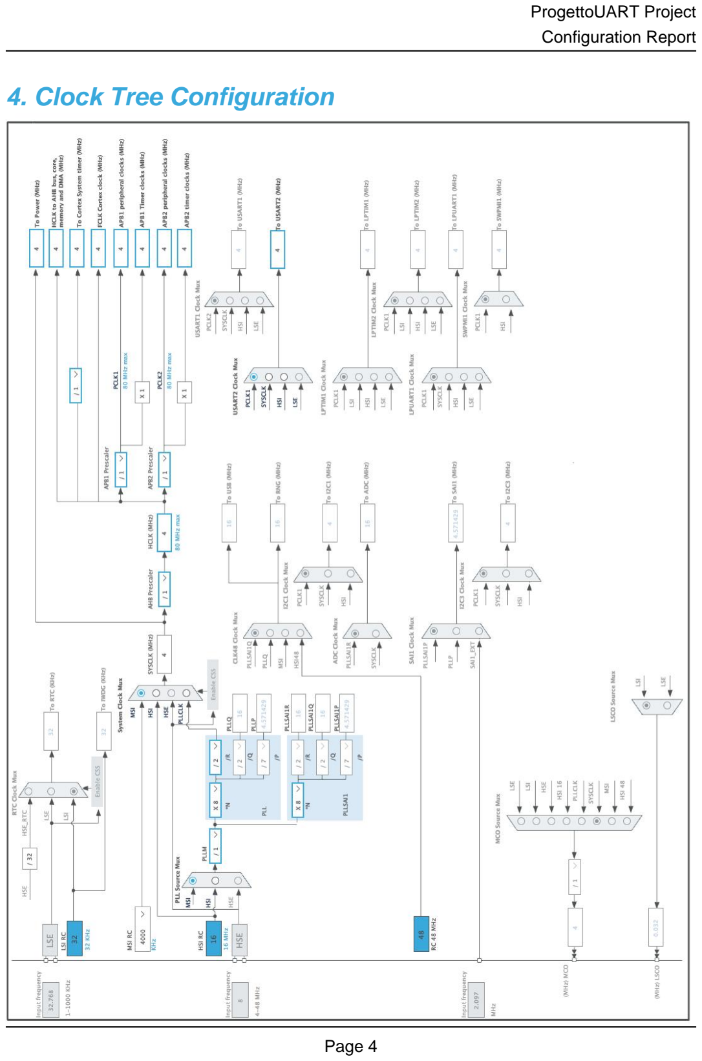
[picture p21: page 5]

## 1. Power Consumption Calculator report

### 1.1. Microcontroller Selection

Series | STM32L4
Line | STM32L4x2
MCU | STM32L432KCUx
Datasheet | DS11451_Rev2

### 1.2. Parameter Selection

Temperature | 25
Vdd | 3.0

### 1.3. Battery Selection

Battery | Li-SOCL2(A3400)
Capacity | 3400.0 mAh
Self Discharge | 0.08 %/month
Nominal Voltage | 3.6 V
Max Cont Current | 100.0 mA
Max Pulse Current | 200.0 mA
Cells in series | 1
Cells in parallel | 1

### 1.4. Sequence

Step | Step1 | Step2
Mode | RUN | STOP2
Vdd | 3.0 | 3.0
Voltage Source | Battery | Battery
Range | Range1-High | NoRange
Fetch Type | SRAM2 | n/a
CPU Frequency | 80 MHz | 0 Hz
Clock Configuration | HSE BYP PLL | ALL CLOCKS OFF
Clock Source Frequency | 4 MHz | 0 Hz
Peripherals
Additional Cons. | 0 mA | 0 mA
Average Current | 8.71 mA | 1.06 µA
Duration | 0.1 ms | 0.9 ms
DMIPS | 100.0 | 0.0
Ta Max | 103.98 | 105
Category | In DS Table | In DS Table

### 1.5. Results

Sequence Time | 1 ms | Average Current | 871.95 µA
Battery Life | 5 months, 9 days, 16 hours | Average DMIPS | 100.0 DMIPS

### 1.6. Chart

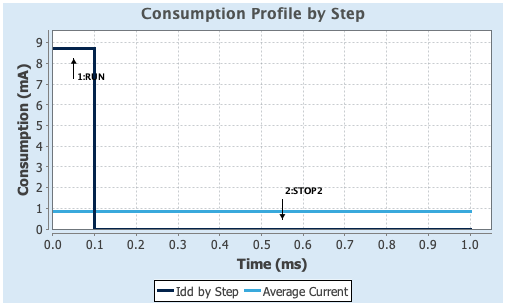
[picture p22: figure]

## 2. Software Project

### 2.1. Project Settings

Name | Value
Project Name | ProgettoUART
Project Folder | /Users/cristianpetramale/Biomed_projects/STMWorkSpace/ProgettoUART
Toolchain / IDE | STM32CubeIDE
Firmware Package Name and Version | STM32Cube FW_L4 V1.18.2
Application Structure | Advanced
Generate Under Root | Yes
Do not generate the main() | No
Minimum Heap Size | 0x200
Minimum Stack Size | 0x400

### 2.2. Code Generation Settings

Name | Value
STM32Cube MCU packages and embedded software | Copy only the necessary library files
Generate peripheral initialization as a pair of '.c/.h' files | No
Backup previously generated files when re-generating | No
Keep User Code when re-generating | Yes
Delete previously generated files when not re-generated | Yes
Set all free pins as analog (to optimize the power consumption) | No
Enable Full Assert | No

### 2.3. Advanced Settings - Generated Function Calls

Rank | Function Name | Peripheral Instance Name
1 | SystemClock_Config | RCC
2 | MX_GPIO_Init | GPIO
3 | MX_USART2_UART_Init | USART2

## 3. Peripherals and Middlewares Configuration

### 3.1. RCC

3.1.1. Parameter Settings:

System Parameters:

VDD voltage (V) | 3.3
Instruction Cache | Enabled
Prefetch Buffer | Disabled
Data Cache | Enabled
Flash Latency(WS) | 0 WS (1 CPU cycle)
RCC Parameters:
HSI Calibration Value | 16
MSI Calibration Value | 0
MSI Auto Calibration | Disabled
HSE Startup Timout Value (ms) | 100
LSE Startup Timout Value (ms) | 5000
Power Parameters:
Power Regulator Voltage Scale | Power Regulator Voltage Scale 1

### 3.2. SYS

Timebase Source: SysTick

### 3.3. USART2

Mode: Asynchronous
3.3.1. Parameter Settings:

Basic Parameters:

Baud Rate | 115200
Word Length | 8 Bits (including Parity)
Parity | None
Stop Bits | 1
Advanced Parameters:
Data Direction | Receive and Transmit
Over Sampling | 16 Samples
Single Sample | Disable
Advanced Features:
Auto Baudrate | Disable
TX Pin Active Level Inversion | Disable

RX Pin Active Level Inversion | Disable
Data Inversion | Disable
TX and RX Pins Swapping | Disable
Overrun | Enable
DMA on RX Error | Enable
MSB First | Disable

* User modified value

## 4. System Configuration

### 4.1. GPIO configuration

IP | Pin | Signal | GPIO mode | GPIO pull/up pull down | Max Speed | User Label
USART2 | PA2 | USART2_TX | Alternate Function Push Pull | No pull-up and no pull-down | Very High *
| PA15 (JTDI) | USART2_RX | Alternate Function Push Pull | No pull-up and no pull-down | Very High *

### 4.2. DMA configuration

nothing configured in DMA service

### 4.3. NVIC configuration

4.3.1. NVIC
Interrupt Table | Enable | Preenmption Priority | SubPriority
Non maskable interrupt | true | 0 | 0
Hard fault interrupt | true | 0 | 0
Memory management fault | true | 0 | 0
Prefetch fault, memory access fault | true | 0 | 0
Undefined instruction or illegal state | true | 0 | 0
System service call via SWI instruction | true | 0 | 0
Debug monitor | true | 0 | 0
Pendable request for system service | true | 0 | 0
System tick timer | true | 15 | 0
PVD/PVM1/PVM2/PVM3/PVM4 interrupts through EXTI lines 16/35/36/37/38 | unused
Flash global interrupt | unused
RCC global interrupt | unused
USART2 global interrupt | unused
FPU global interrupt | unused
4.3.2. NVIC Code generation
Enabled interrupt Table | Select for init sequence ordering | Generate IRQ handler | Call HAL handler
Non maskable interrupt | false | true | false
Hard fault interrupt | false | true | false
Memory management fault | false | true | false
Prefetch fault, memory access fault | false | true | false
Undefined instruction or illegal state | false | true | false
System service call via SWI instruction | false | true | false
Debug monitor | false | true | false
Pendable request for system service | false | true | false
System tick timer | false | true | true

* User modified value

## 5. System Views

5.1. Category view
5.1.1. Current

## 6. Docs & Resources

Type | Link
BSDL files | https://www.st.com/resource/en/bsdl_model/stm32l4_bsdl.zip
IBIS models | https://www.st.com/resource/en/ibis_model/stm32l4_ibis.zip
System View Description | https://www.st.com/resource/en/svd/stm32l4_svd.zip
Presentations | https://www.st.com/resource/en/product_presentation/stm32-stm8_embedded_software_solutions.pdf
Presentations | https://www.st.com/resource/en/product_presentation/stm32_eval-tools_portfolio.pdf
Presentations | https://www.st.com/resource/en/product_presentation/stm32_stm8_functi onal-safety-packages.pdf
Presentations | https://www.st.com/resource/en/product_presentation/stm32-stm8_software_development_tools.pdf
Presentations | https://www.st.com/resource/en/product_presentation/microcontrollers_b-l462e-cell1_discovery_cellular_kit_product_overview.pdf
Presentations | https://www.st.com/resource/en/product_presentation/microcontrollers-stm32-family-overview.pdf
Presentations | https://www.st.com/resource/en/product_presentation/microcontrollers-stm32l4-series-product-overview.pdf
Brochures | https://www.st.com/resource/en/brochure/brstm32ulp.pdf
Flyers | https://www.st.com/resource/en/flyer/flstm32l4.pdf
Flyers | https://www.st.com/resource/en/flyer/flstm32nucleo.pdf
Flyers | https://www.st.com/resource/en/flyer/flstm32trust.pdf
Magazine Articles | https://www.st.com/resource/en/magazine/design-elektronik_august2017.pdf
Magazine Articles | https://www.st.com/resource/en/magazine/design-elektronik_october2016.pdf
Product Certifications | https://www.st.com/resource/en/certification_document/sesip-2000002-01-cert.pdf
Product | https://www.st.com/resource/en/certification_document/sesip-2000002-

Certifications | 01-st2.pdf
Product Certifications | https://www.st.com/resource/en/certification_document/psa-certificate_stm32l4.pdf
Security Bulletin | https://www.st.com/resource/en/technical_note/tn1489-security-bulletin-tn1489stpsirt-physical-attacks-on-stm32-and-stm32cube-firmware-stmicroelectronics.pdf
Application Notes | https://www.st.com/resource/en/application_note/an1709-emc-design-guide-for-stm8-stm32-and-legacy-mcus-stmicroelectronics.pdf
Application Notes | https://www.st.com/resource/en/application_note/an3126-audio-and-waveform-generation-using-the-dac-in-stm32-products-stmicroelectronics.pdf
Application Notes | https://www.st.com/resource/en/application_note/an3155-usart-protocol-used-in-the-stm32-bootloader-stmicroelectronics.pdf
Application Notes | https://www.st.com/resource/en/application_note/an3156-usb-dfu-protocol-used-in-the-stm32-bootloader-stmicroelectronics.pdf
Application Notes | https://www.st.com/resource/en/application_note/an4221-i2c-protocol-used-in-the-stm32-bootloader-stmicroelectronics.pdf
Application Notes | https://www.st.com/resource/en/application_note/an4286-spi-protocol-used-in-the-stm32-bootloader-stmicroelectronics.pdf
Application Notes | https://www.st.com/resource/en/application_note/an4555-getting-started-with-stm32l4-series-and-stm32l4-series-hardware-development-stmicroelectronics.pdf
Application Notes | https://www.st.com/resource/en/application_note/an4612-migrating-from-stm32l1-series-to-stm32l4-series-and-stm32l4-series-microcontrollers-stmicroelectronics.pdf
Application Notes | https://www.st.com/resource/en/application_note/an4616-migrating-from-stm32f401-and-stm32f411-lines-to-stm32l4-series-and-stm32l4-series-microcontrollers-stmicroelec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
Application Notes | https://www.st.com/resource/en/application_note/an4621-stm32l4-and-stm32l4-ultralowpower-features-overview-stmicroelectronics.pdf
Application Notes | https://www.st.com/resource/en/application_note/an4629-adc-hardware-oversampling-for-microcontrollers-of-the-stm32-l0-and-l4-series-stmicroelectronics.pdf

Application Notes | https://www.st.com/resource/en/application_note/an4649-migrating-from-stm32f1-series-to-stm32l4-series--stm32l4-series-microntrollers-stmicroelectronics.pdf
Application Notes | https://www.st.com/resource/en/application_note/an4655-virtually-increasing-the-number-of-serial-communication-peripherals-in-stm32-applications-stmicroelectronics.p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
Application Notes | https://www.st.com/resource/en/application_note/an4726-stm32cube-firmware-examples-for-stm32l4-series-and-stm32l4-series-stmicroelectronics.pdf
Application Notes | https://www.st.com/resource/en/application_note/an4729-stm32l0l4-firewall-overview-stmicroelectronics.pdf
Application Notes | https://www.st.com/resource/en/application_note/an4730-using-the-firewall-embedded-in-stm32l0l4l4-series-mcus-for-secure-access-to-sensitive-parts-of-code-and-data-s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
Application Notes | https://www.st.com/resource/en/application_note/an4746-optimizing-power-and-performance-with-stm32l4-and-stm32l4-series-microcontrollers-stmicroelectronics.pdf
Application Notes | https://www.st.com/resource/en/application_note/an4750-handling-of-soft-errors-in-stm32-applications-stmicroelectronics.pdf
Application Notes | https://www.st.com/resource/en/application_note/an4776-generalpurpose-timer-cookbook-for-stm32-microcontrollers-stmicroelectronics.pdf
Application Notes | https://www.st.com/resource/en/application_note/an4803-highspeed-si-simulations-using-ibis-and-boardlevel-simulations-using-hyperlynx-si-on-stm32-mcus-and-mpus-stmic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
Application Notes | https://www.st.com/resource/en/application_note/an4809-migrating-between-stm32l0-series-and-stm32l4-series--stm32l4-series-microcontrollers-stmicroelectronics.pdf
Application Notes | https://www.st.com/resource/en/application_note/an4821-migrating-from-stm32f405415-line-and-stm32f407417-line-to-stm32l4-series-and-stm32l4-series-microcontrollers-s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
Application Notes | https://www.st.com/resource/en/application_note/an4831-migrating-from-stm32f2x5-line-to-stm32l4-series-and-stm32l4-series-microcontrollers-stmicroelectronics.pdf
Application Notes | https://www.st.com/resource/en/application_note/an4832-migrating-from-

| stm32f303-line-to-stm32l4-series-and-stm32l4-series-microcontrollers-stmicroelectronics.pdf
Application Notes | https://www.st.com/resource/en/application_note/an4989-stm32-microcontroller-debug-toolbox-stmicroelectronics.pdf
Application Notes | https://www.st.com/resource/en/application_note/an4990-getting-started-with-sigmadelta-digital-interface-on-applicable-stm32-microcontrollers-stmicroelectronics.pdf
Application Notes | https://www.st.com/resource/en/application_note/an4995-using-an-electromyogram-technique-to-detect-muscle-activity-stmicroelectronics.pdf
Application Notes | https://www.st.com/resource/en/application_note/an5012-analogtodigital-audio-conversion-example-using-stm32l4-series-microcontroller-peripherals-stmicroelectronics.p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
Application Notes | https://www.st.com/resource/en/application_note/an5027-interfacing-pdm-digital-microphones-using-stm32-mcus-and-mpus-stmicroelectronics.pdf
Application Notes | https://www.st.com/resource/en/application_note/an5138-migrating-from-stm32l4-and-stm32l4-to-stm32l5-series-microcontrollers-stmicroelectronics.pdf
Application Notes | https://www.st.com/resource/en/application_note/an4760-quadspi-interface-on-stm32-microcontrollers-and-microprocessors--stmicroelectronics.pdf
Application Notes | https://www.st.com/resource/en/application_note/an4899-stm32-microcontroller-gpio-hardware-settings-and-lowpower-consumption-stmicroelectronics.pdf
Application Notes | https://www.st.com/resource/en/application_note/an5612-esd-protection-of-stm32-mcus-and-mpus-stmicroelectronics.pdf
Application Notes | https://www.st.com/resource/en/application_note/an4991-how-to-wake-up-an-stm32-microcontroller-from-lowpower-mode-with-the-usart-or-the-lpuart-stmicroelectronics.pdf
Application Notes | https://www.st.com/resource/en/application_note/an4838-introduction-to-memory-protection-unit-management-on-stm32-mcus-stmicroelectronics.pdf
Application Notes | https://www.st.com/resource/en/application_note/an4879-introduction-to- usb-hardware-and-pcb-guidelines-using-stm32-mcus-

| stmicroelectronics.pdf
Application Notes | https://www.st.com/resource/en/application_note/an5372-migrating-from-stm32l4-and-stm32l4--to-stm32u5-mcus-stmicroelectronics.pdf
Application Notes | https://www.st.com/resource/en/application_note/an5225-introduction-to-usb-typec-power-delivery-for-stm32-mcus-and-mpus-stmicroelectronics.pdf
Application Notes | https://www.st.com/resource/en/application_note/an4777-how-to-optimize-power-consumption-on-stm32-mcus-stmicroelectronics.pdf
Application Notes | https://www.st.com/resource/en/application_note/an4894-how-to-use-eeprom-emulation-on-stm32-mcus-stmicroelectronics.pdf
Application Notes | https://www.st.com/resource/en/application_note/an5537-how-to-use-adc-oversampling-techniques-to-improve-signaltonoise-ratio-on-stm32-mcus-stmicroelectronics.pdf
Application Notes | https://www.st.com/resource/en/application_note/an5036-guidelines-for-thermal-management-on-stm32-applications-stmicroelectronics.pdf
Application Notes | https://www.st.com/resource/en/application_note/an5690-how-to-use-vrefbuf-peripheral-on-stm32-mcus-and-mpus-stmicroelectronics.pdf
Application Notes | https://www.st.com/resource/en/application_note/an4230-introduction-to-random-number-generation-validation-using-the-nist-statistical-test-suite-for-stm32-mcus-and-m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
Application Notes | https://www.st.com/resource/en/application_note/an2548-introduction-to-dma-controller-for-stm32-mcus-stmicroelectronics.pdf
Application Notes | https://www.st.com/resource/en/application_note/an2867-guidelines-for-oscillator-design-on-stm8afals-and-stm32-mcusmpus-stmicroelectronics.pdf
Application Notes | https://www.st.com/resource/en/application_note/an3236-how-to-increase-the-number-of-touchkeys-for-touch-sensing-applications-on-stm32-mcus-stmicroelectronics.pdf
Application Notes | https://www.st.com/resource/en/application_note/an3960-guidelines-for-esd-for-touch-sensing-applications-on-stm32-mcus-stmicroelectronics.pdf
Application Notes | https://www.st.com/resource/en/application_note/an4013-introduction-to-timers-for-stm32-mcus-stmicroelectronics.pdf
Application Notes | https://www.st.com/resource/en/application_note/an4277-how-to-use-

| pwm-shutdown-for-motor-control-and-digital-power-conversion-on-stm32-mcus-stmicroelectronics.pdf
Application Notes | https://www.st.com/resource/en/application_note/an4299-how-to-improve-conducted-noise-robustness-for-touch-sensing-applications-on-stm32-mcus-stmicroelectronics.pdf
Application Notes | https://www.st.com/resource/en/application_note/an4310-how-to-choose-the-sampling-capacitor-for-touch-sensing-applications-on-stm32-mcus-stmicroelectronics.pdf
Application Notes | https://www.st.com/resource/en/application_note/an4312-how-to-design-surface-sensors-for-touch-sensing-applications-on-stm32-mcus-stmicroelectronics.pdf
Application Notes | https://www.st.com/resource/en/application_note/an4316-how-to-tune-touch-sensing-applications-on-stm32-mcus-stmicroelectronics.pdf
Application Notes | https://www.st.com/resource/en/application_note/an4635-how-to-optimize-lpuart-power-consumption-on-stm32-mcus-stmicroelectronics.pdf
Application Notes | https://www.st.com/resource/en/application_note/an4759-introduction-to-using-the-hardware-realtime-clock-rtc-and-the-tamper-management-unit-tamp-with-stm32-mcus-stmi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
Application Notes | https://www.st.com/resource/en/application_note/an4908-getting-started-with-usart-automatic-baud-rater-detection-for-stm32-mcus-stmicroelectronics.pdf
Application Notes | https://www.st.com/resource/en/application_note/an5156-introduction-to-security-for-stm32-mcus-stmicroelectronics.pdf
Application Notes | https://www.st.com/resource/en/application_note/an5543-guidelines-for-enhanced-spi-communication-on-stm32-mcus-and-mpus-stmicroelectronics.pdf
Application Notes | https://www.st.com/resource/en/application_note/cd00211314-how-to-optimize-the-adc-accuracy-in-the-stm32-mcus-stmicroelectronics.pdf
Application Notes | https://www.st.com/resource/en/application_note/an2639-soldering-recommendations-and-package-information-for-leadfree-ecopack2-mcus-and-mpus-stmicroelectronics.pdf
Application Notes | https://www.st.com/resource/en/application_note/an3154-how-to-use-can-protocol-in-bootloader-on-stm32-mcus-stmicroelectronics.pdf

Application Notes | https://www.st.com/resource/en/application_note/an6099-migrating-from-stm32l4-to-stm32u0-mcus-stmicroelectronics.pdf
Application Notes | https://www.st.com/resource/en/application_note/an4566-how-to-extend-the-dac-performance-on-stm32-mcus-stmicroelectronics.pdf
Application Notes | https://www.st.com/resource/en/application_note/an5105-getting-started-with-touch-sensing-control-on-stm32-mcus-stmicroelectronics.pdf
Application Notes | https://www.st.com/resource/en/application_note/an5408-migrating-from-stm32l0-stm32l1-and-stm32l4-series-associated-with-sx12xx-transceiver-to-stm32wl5xex-microcontr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
Application Notes | https://www.st.com/resource/en/application_note/an6051-migrating-from-stm32l4-and-stm32l4-to-stm32u3-mcus-stmicroelectronics.pdf
Application Notes | https://www.st.com/resource/en/application_note/an5647-the-goertzel-algorithm-to-compute-individual-terms-of-the-discrete-fourier-transform-dft-in-stm32-products-stm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
Application Notes | https://www.st.com/resource/en/application_note/an2606-introduction-to-system-memory-boot-mode-on-stm32-mcus-stmicroelectronics.pdf
Application Notes for related Tools & Software | https://www.st.com/resource/en/application_note/an4044-floating-point-unit-demonstration-on-stm32-microcontrollers-stmicroelectronics.pdf
Application Notes for related Tools & Software | https://www.st.com/resource/en/application_note/an4323-getting-started-with-stemwin-library-stmicroelectronics.pdf
Application Notes for related Tools & Software | https://www.st.com/resource/en/application_note/an4435-guidelines-for-obtaining-ulcsaiec-607301603351-class-b-certification-in-any-stm32-application-stmicroelectroni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
Application Notes for related Tools & Software | https://www.st.com/resource/en/application_note/an4631-how-to-calibrate-an-stm32l0xx-internal-rc-oscillator-stmicroelectronics.pdf
Application Notes for related Tools & Software | https://www.st.com/resource/en/application_note/an4657-stm32-inapplication-programming-iap-using-the-usart-stmicroelectronics.pdf
Application Notes for related Tools & Software | https://www.st.com/resource/en/application_note/an4666-parallel-synchronous-transmission-using-gpio-and-dma-stmicroelectronics.pdf

Application Notes for related Tools & Software | https://www.st.com/resource/en/application_note/an4701-proprietary-code-readout-protection-on-microcontrollers-of-the-stm32f4-series-stmicroelectronics.pdf
Application Notes for related Tools & Software | https://www.st.com/resource/en/application_note/an4726-stm32cube-firmware-examples-for-stm32l4-series-and-stm32l4-series-stmicroelectronics.pdf
Application Notes for related Tools & Software | https://www.st.com/resource/en/application_note/an4736-how-to-calibrate-stm32l4-series-microcontrollers-internal-rc-oscillator-stmicroelectronics.pdf
Application Notes for related Tools & Software | https://www.st.com/resource/en/application_note/an4758-proprietary-code-readout-protection-on-stm32l4-stm32l4-stm32g4-and-stm32wb-series-mcus-stmicroelectronics.pdf
Application Notes for related Tools & Software | https://www.st.com/resource/en/application_note/an4767-onthefly-firmware-update-for-dual-bank-stm32-microcontrollers-stmicroelectronics.pdf
Application Notes for related Tools & Software | https://www.st.com/resource/en/application_note/an4834-implementation-of-transmitters-and-receivers-for-infrared-remote-control-protocols-with-stm32cube-stmicroelect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
Application Notes for related Tools & Software | https://www.st.com/resource/en/application_note/an4841-digital-signal-processing-for-stm32-microcontrollers-using-cmsis-stmicroelectronics.pdf
Application Notes for related Tools & Software | https://www.st.com/resource/en/application_note/an4968-proprietary-code-read-out-protection-pcrop-on-stm32f72xxx-and-stm32f73xxx-microcontrollers-stmicroelectronics.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
Application Notes for related Tools & Software | https://www.st.com/resource/en/application_note/an5056-integration-guide-for-the-xcubesbsfu-stm32cube-expansion-package-stmicroelectronics.pdf
Application Notes for related Tools & Software | https://www.st.com/resource/en/application_note/an5282-using-xcuberccalib-software-to-calibrate-stm32wb-series-internal-rc-oscillators-stmicroelectronics.pdf
Application Notes for related Tools & Software | https://www.st.com/resource/en/application_note/an5360-getting-started-with-projects-based-on-the-stm32mp1-series-in-stm32cubeide-stmicroelectronics.pdf
Application Notes | https://www.st.com/resource/en/application_note/an5361-getting-started-

for related Tools & Software | with-projects-based-on-dualcore-stm32h7-microcontrollers-in-stm32cubeide-stmicroelectronics.pdf
Application Notes for related Tools & Software | https://www.st.com/resource/en/application_note/an5394-getting-started-with-projects-based-on-the-stm32l5-series-in-stm32cubeide-stmicroelectronics.pdf
Application Notes for related Tools & Software | https://www.st.com/resource/en/application_note/an5418-how-to-build-a-simple-usbpd-sink-application-with-stm32cubemx-stmicroelectronics.pdf
Application Notes for related Tools & Software | https://www.st.com/resource/en/application_note/an5426-migrating-graphics-middleware-projects-from-stm32cubemx-540-to-stm32cubemx-550-stmicroelectronics.pdf
Application Notes for related Tools & Software | https://www.st.com/resource/en/application_note/an5564-getting-started-with-projects-based-on-dualcore-stm32wl-microcontrollers-in-stm32cubeide-stmicroelectronics.pd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
Application Notes for related Tools & Software | https://www.st.com/resource/en/application_note/an4865-lowpower-timer-lptim-applicative-use-cases-on-stm32-mcus-and-mpus-stmicroelectronics.pdf
Application Notes for related Tools & Software | https://www.st.com/resource/en/application_note/an5698-adapting-the-xcubestl-functional-safety-package-for-stm32-iec-61508-compliant-to-other-safety-standards-stmicr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
Application Notes for related Tools & Software | https://www.st.com/resource/en/application_note/an5731-stm32cubemx-and-stm32cubeide-threadsafe-solution-stmicroelectronics.pdf
Application Notes for related Tools & Software | https://www.st.com/resource/en/application_note/an5857-using-xcuberccalib-software-to-calibrate-stm32c0-series-internal-rc-oscillator-stmicroelectronics.pdf
Application Notes for related Tools & Software | https://www.st.com/resource/en/application_note/an4502-stm32-smbuspmbus-expansion-package-for-stm32cube-stmicroelectronics.pdf
Application Notes for related Tools & Software | https://www.st.com/resource/en/application_note/an5126-how-to-calibrate-internal-oscillators-on-stm32g0-mcus-stmicroelectronics.pdf

Application Notes
for related Tools

https://www.st.com/resource/en/application_note/an4777-how-tooptimize-power-consumption-on-stm32-mcus-stmicroelectronics.pdf

& Software
Application Notes for related Tools & Software | https://www.st.com/resource/en/application_note/an5952-how-to-use-cmake-in-stm32cubeide-stmicroelectronics.pdf
Application Notes for related Tools & Software | https://www.st.com/resource/en/application_note/an4894-how-to-use-eeprom-emulation-on-stm32-mcus-stmicroelectronics.pdf
Application Notes for related Tools & Software | https://www.st.com/resource/en/application_note/an4635-how-to-optimize-lpuart-power-consumption-on-stm32-mcus-stmicroelectronics.pdf
Application Notes for related Tools & Software | https://www.st.com/resource/en/application_note/an5054-how-to-perform-secure-programming-using-stm32cubeprogrammer-stmicroelectronics.pdf
Application Notes for related Tools & Software | https://www.st.com/resource/en/application_note/an6179-how-to-integrate-the-stl-firmware-into-a-time-critical-user-application-stmicroelectronics.pdf
Application Notes for related Tools & Software | https://www.st.com/resource/en/application_note/an6202-how-to-calibrate-internal-rc-oscillators-on-stm32h5-mcus-stmicroelectronics.pdf
Application Notes for related Tools & Software | https://www.st.com/resource/en/application_note/an5676-how-to-calibrate-internal-rc-oscillators-on-stm32u3-and-stm32u5-series-mcus-stmicroelectronics.pdf
Application Notes for related Tools & Software | https://www.st.com/resource/en/application_note/an6127-getting-started-with-stm32h7rx7sx-mcus-in-stm32cubeide-stmicroelectronics.pdf
Application Notes for related Tools & Software | https://www.st.com/resource/en/application_note/an6265-getting-started-with-stm32n6-mcus-in-stm32cubeide-stmicroelectronics.pdf
Application Notes for related Tools & Software | https://www.st.com/resource/en/application_note/an6382-introduction-to-swd-multidrop-for-stm32-with-stlink-stmicroelectronics.pdf
Errata Sheets | https://www.st.com/resource/en/errata_sheet/es0318-stm32l431xx432xx433xx442xx443xx-device-errata-stmicroelectronics.pdf
Datasheet | https://www.st.com/resource/en/datasheet/dm00257205.pdf

Programming Manuals | https://www.st.com/resource/en/programming_manual/pm0214-stm32-cortexm4-mcus-and-mpus-programming-manual-stmicroelectronics.pdf
Reference Manuals | https://www.st.com/resource/en/reference_manual/rm0394-stm32l41xxx42xxx43xxx44xxx45xxx46xxx-advanced-armbased-32bit-mcus-stmicroelectronics.pdf
Technical Notes & Articles | https://www.st.com/resource/en/technical_note/tn1163-description-of-wlcsp-for-microcontrollers-and-recommendations-for-its-use-stmicroelectronics.pdf
Technical Notes & Articles | https://www.st.com/resource/en/technical_note/tn1204-tape-and-reel-shipping-media-for-stm32-microcontrollers-in-bga-packages-stmicroelectronics.pdf
Technical Notes & Articles | https://www.st.com/resource/en/technical_note/tn1205-tape-and-reel-shipping-media-for-stm8-and-stm32-microcontrollers-in-fpn-packages-stmicroelectronics.pdf
Technical Notes & Articles | https://www.st.com/resource/en/technical_note/tn1206-tape-and-reel-shipping-media-for-stm8-and-stm32-microcontrollers-in-qfp-packages-stmicroelectronics.pdf
Technical Notes & Articles | https://www.st.com/resource/en/technical_note/tn1207-tape-and-reel-shipping-media-for-stm8-and-stm32-microcontrollers-in-so-packages-stmicroelectronics.pdf
Technical Notes & Articles | https://www.st.com/resource/en/technical_note/tn1208-tape-and-reel-shipping-media-for-stm8-and-stm32-microcontrollers-in-tssop-and-ssop-packages-stmicroelectronics.p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
Technical Notes & Articles | https://www.st.com/resource/en/technical_note/tn1433-reference-device-marking-schematics-for-stm32-microcontrollers-and-microprocessors-stmicroelectronics.pdf
User Manuals | https://www.st.com/resource/en/user_manual/um2305-stm32l4-and-stm32l4-series-safety-manual-stmicroelectronics.pdf
User Manuals | https://www.st.com/resource/en/user_manual/um3166-stm32l4-and-stm32l4-series-ulcsaiec-607301603351-selftest-library-user-guide-stmicroelectronics.pdf

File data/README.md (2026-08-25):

# Measurement data

The `measurements/raw/` directory contains the original experimental acquisitions collected during system characterization.

The files are preserved in their original form. They were generated by different software iterations and therefore do not all share the same column names, units or metadata format. The MATLAB scripts used for interpolation and resistance analysis are in [analysis/matlab](../analysis/matlab/).

Generated logs and analysis outputs are excluded by the root `.gitignore`. Raw acquisitions are kept because they document the experimental work behind the project.

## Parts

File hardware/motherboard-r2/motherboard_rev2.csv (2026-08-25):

Reference | Qty | Value | DNP | Footprint | JLC | LCSC Part # | VRATE
C1 | 1 | 4u7 |  | Capacitor_SMD:C_1206_3216Metric_Pad1.33x1.80mm_HandSolder | C29823 |  | 50
C2 | 1 | 6n8 |  | Capacitor_SMD:C_1206_3216Metric_Pad1.33x1.80mm_HandSolder | C1879 |  | 50
C5,C32,C33,C34,C35 | 5 | 100n |  | Capacitor_SMD:C_1206_3216Metric_Pad1.33x1.80mm_HandSolder | C24497 |  | 16,50
C8 | 1 | 1n8 |  | Capacitor_SMD:C_1206_3216Metric_Pad1.33x1.80mm_HandSolder | C527250 |  | 50
C9 | 1 | 1p2 |  | Capacitor_SMD:C_1206_3216Metric_Pad1.33x1.80mm_HandSolder | C5448986 |  | 50
C10,C25,L1 | 3 | 47u |  | Capacitor_SMD:C_1206_3216Metric_Pad1.33x1.80mm_HandSolder,inductors:IND-SMD_L13.5-W12.6_125CDMCC-DS | C357265,C92821 |  | 10
C11,C12,C14 | 3 | 1u |  | Capacitor_SMD:C_1206_3216Metric_Pad1.33x1.80mm_HandSolder | C28322 |  | 16
C15,C16,C17 | 3 | 150p |  | Capacitor_SMD:C_1206_3216Metric_Pad1.33x1.80mm_HandSolder | C282831 |  | 50
C18,C19,C20 | 3 | 330p |  | Capacitor_SMD:C_1206_3216Metric_Pad1.33x1.80mm_HandSolder | C106055 |  | 50
C24 | 1 | 220u |  | Capacitor_SMD:C_Elec_10x10.2 | C3358 |  | 50
D1 | 1 | SMAJ26A |  | Diode_SMD:D_SMA | C49370
D2 | 1 | SS24FL |  | diodes:SMA_L4.4-W2.8-LS5.4-RD | C111630
D3 | 1 | LED_ORANGE |  | LED_SMD:LED_1206_3216Metric_Pad1.42x1.75mm_HandSolder | C130716
D6 | 1 | LED_BLUE |  | LED_SMD:LED_1206_3216Metric_Pad1.42x1.75mm_HandSolder | C125088
D7 | 1 | LED_YELLOW |  | LED_SMD:LED_1206_3216Metric_Pad1.42x1.75mm_HandSolder | C2298
D8 | 1 | LED_GREEN |  | LED_SMD:LED_1206_3216Metric_Pad1.42x1.75mm_HandSolder | C264329
E1 | 1 | escon |  | escon50_5:escon_vero
J1 | 1 | Conn_01x04 |  | TerminalBlock_Phoenix:TerminalBlock_Phoenix_MPT-0,5-4-2.54_1x04_P2.54mm_Horizontal
J2,J8 | 2 | Conn_01x06 |  | TerminalBlock_Phoenix:TerminalBlock_Phoenix_MPT-0,5-6-2.54_1x06_P2.54mm_Horizontal
J3 | 1 | Conn_01x08 |  | TerminalBlock_Phoenix:TerminalBlock_Phoenix_MPT-0,5-8-2.54_1x08_P2.54mm_Horizontal
J5,J6 | 2 | Conn_01x03 |  | TerminalBlock_Phoenix:TerminalBlock_Phoenix_MPT-0,5-3-2.54_1x03_P2.54mm_Horizontal
J7,J11 | 2 | Conn_01x05 |  | TerminalBlock_Phoenix:TerminalBlock_Phoenix_MPT-0,5-5-2.54_1x05_P2.54mm_Horizontal
J9,J13,J14,J16 | 4 | Conn_01x02 |  | TerminalBlock_Phoenix:TerminalBlock_Phoenix_MKDS-3-2-5.08_1x02_P5.08mm_Horizontal,TerminalBlock_Phoenix:TerminalBlock_Phoenix_MPT-0,5-2-2.54_1x02_P2.54mm_Horizontal
J10 | 1 | Screw_Terminal_01x03 |  | TerminalBlock_Phoenix:TerminalBlock_Phoenix_PT-1,5-3-5.0-H_1x03_P5.00mm_Horizontal
L2,L3,L4 | 3 | 22uH |  | inductors:IND-SMD_L17.0-W17.0_YSPIA1770-100M | C5122901
Q3 | 1 | NMOS |  | transistors:SOT-23-3_L2.9-W1.3-P1.90-LS2.4-BR | C8545
R1 | 1 | 249k |  | Resistor_SMD:R_1206_3216Metric_Pad1.30x1.75mm_HandSolder | C34578
R2 | 1 | 390 ohm |  | Resistor_SMD:R_1206_3216Metric_Pad1.30x1.75mm_HandSolder | C4491
R3,R4 | 2 | 4.7K |  | Resistor_SMD:R_1206_3216Metric_Pad1.30x1.75mm_HandSolder | C17936
R7 | 1 | 133k |  | Resistor_SMD:R_1206_3216Metric_Pad1.30x1.75mm_HandSolder | C159706
R8 | 1 | 52k3 |  | Resistor_SMD:R_1206_3216Metric_Pad1.30x1.75mm_HandSolder | C245568
R9,R10,R14,R15,R19,R20,R31 | 7 | 10k |  | Resistor_SMD:R_1206_3216Metric_Pad1.30x1.75mm_HandSolder | C1489
R16,R17,R18 | 3 | 390 |  | Resistor_SMD:R_1206_3216Metric_Pad1.30x1.75mm_HandSolder | C4491
R22,R23,R26 | 3 | 10K |  | Resistor_SMD:R_1206_3216Metric_Pad1.30x1.75mm_HandSolder | C1489
R29 | 1 | 105k |  | Resistor_SMD:R_1206_3216Metric_Pad1.30x1.75mm_HandSolder | C247404
R30 | 1 | 6k49 |  | Resistor_SMD:R_1206_3216Metric_Pad1.30x1.75mm_HandSolder | C229768
R32 | 1 | 1k |  | Resistor_SMD:R_1206_3216Metric_Pad1.30x1.75mm_HandSolder | C4410
TP1 | 1 | TestPoint |  | TestPoint:TestPoint_Pad_D2.5mm
U1 | 1 | TPS54140ADGQR |  | dgq10:DGQ10_1P88X1P57_TEX | C20607218
U2 | 1 | NODEMCU-32S |  | NODEMCU-32S:MODULE_NODEMCU-32S
U3 | 1 | AP2112K-3.3TRG1 |  | SOT_RG1:SOT_RG1_DIO | C51118
U6 | 1 | TXS0104EPWR |  | TXS0104EPWR:SOP65P640X120-14N | C44955
U9 | 1 | 25LC256-I/SN |  | 25LC256-ISN:SOIC8-N_MC_MCH | C84670
U10 | 1 | AM26LS32ACDR |  | AM26LS32ACDR:D16 | C6180

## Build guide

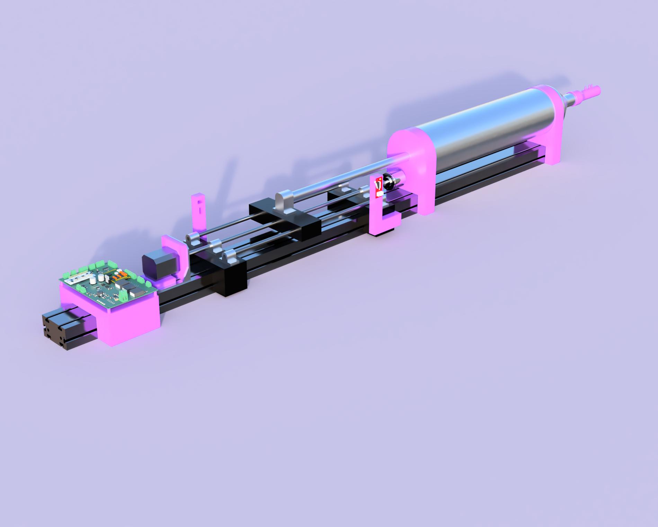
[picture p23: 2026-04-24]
mechanical/renders/syringe-assembly.jpg

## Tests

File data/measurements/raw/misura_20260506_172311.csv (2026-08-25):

--- RIEPILOGO MISURAZIONE ---
Pressione Media (Pa) | 24.20
Tempo di Misura (s) | 6.640
Capacita di Riferimento (L) | 2.915
Flusso Medio (L/s) | 0.439
Time_s | Pressure_Pa
0.920 | 0.57
0.940 | 0.67
0.960 | 0.37
0.980 | 1.12
1.000 | 8.58
1.020 | 34.38
1.040 | 38.85
1.060 | 39.47
1.080 | 34.25
1.100 | 23.37
1.120 | 20.58
1.140 | 23.18
1.160 | 27.30
1.180 | 27.52
1.200 | 24.15
1.220 | 22.10
1.240 | 22.48
1.260 | 23.67
1.280 | 24.93
1.300 | 24.93
1.320 | 25.90
1.340 | 26.65
1.360 | 27.85
1.380 | 29.22
1.400 | 31.52
1.420 | 31.03
1.440 | 29.47
1.460 | 28.07
1.480 | 28.85
1.500 | 28.07
1.520 | 29.22
1.540 | 28.62
1.560 | 27.73
1.580 | 26.98
1.600 | 27.30
1.620 | 26.23
1.640 | 25.68
1.660 | 25.37
1.680 | 23.67
1.700 | 21.90
1.720 | 20.23
1.740 | 18.95
1.760 | 17.90
1.780 | 17.12
1.800 | 15.35
1.820 | 13.78
1.840 | 12.57
1.860 | 12.07
1.880 | 13.00
1.900 | 13.20
1.920 | 13.52
1.940 | 14.50
1.960 | 17.20
1.980 | 19.45
2.000 | 20.15
2.020 | 20.75
2.040 | 20.67
2.060 | 20.67
2.080 | 20.75
2.100 | 20.32
2.120 | 20.67
2.140 | 21.73
2.160 | 21.37
2.180 | 20.23
2.200 | 19.20
2.220 | 20.05
2.240 | 21.28
2.260 | 22.30
2.280 | 23.08
2.300 | 23.07
2.320 | 23.08
2.340 | 22.58
2.360 | 22.20
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

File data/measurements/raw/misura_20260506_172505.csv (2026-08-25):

--- RIEPILOGO MISURAZIONE ---
Pressione Media (Pa) | 25.92
Tempo di Misura (s) | 6.280
Capacita di Riferimento (L) | 2.915
Flusso Medio (L/s) | 0.464
Time_s | Pressure_Pa
0.860 | 0.73
0.880 | 1.17
0.900 | 2.62
0.920 | 21.13
0.940 | 29.20
0.960 | 30.18
0.980 | 26.98
1.000 | 21.85
1.020 | 19.90
1.040 | 22.10
1.060 | 27.73
1.080 | 29.47
1.100 | 26.87
1.120 | 23.47
1.140 | 23.27
1.160 | 21.83
1.180 | 20.75
1.200 | 18.87
1.220 | 19.63
1.240 | 20.78
1.260 | 23.37
1.280 | 25.45
1.300 | 24.55
1.320 | 26.87
1.340 | 30.18
1.360 | 33.05
1.380 | 33.45
1.400 | 33.88
1.420 | 33.45
1.440 | 29.45
1.460 | 25.90
1.480 | 25.25
1.500 | 26.77
1.520 | 26.00
1.540 | 25.68
1.560 | 25.80
1.580 | 26.22
1.600 | 24.73
1.620 | 22.98
1.640 | 22.52
1.660 | 24.63
1.680 | 25.37
1.700 | 23.47
1.720 | 21.12
1.740 | 21.37
1.760 | 22.10
1.780 | 23.27
1.800 | 22.38
1.820 | 21.20
1.840 | 21.20
1.860 | 20.77
1.880 | 21.20
1.900 | 21.55
1.920 | 22.20
1.940 | 21.63
1.960 | 21.63
1.980 | 21.82
2.000 | 22.50
2.020 | 22.68
2.040 | 22.10
2.060 | 22.30
2.080 | 22.88
2.100 | 23.07
2.120 | 24.47
2.140 | 25.35
2.160 | 24.15
2.180 | 23.47
2.200 | 24.83
2.220 | 25.67
2.240 | 24.93
2.260 | 24.25
2.280 | 25.13
2.300 | 25.50
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

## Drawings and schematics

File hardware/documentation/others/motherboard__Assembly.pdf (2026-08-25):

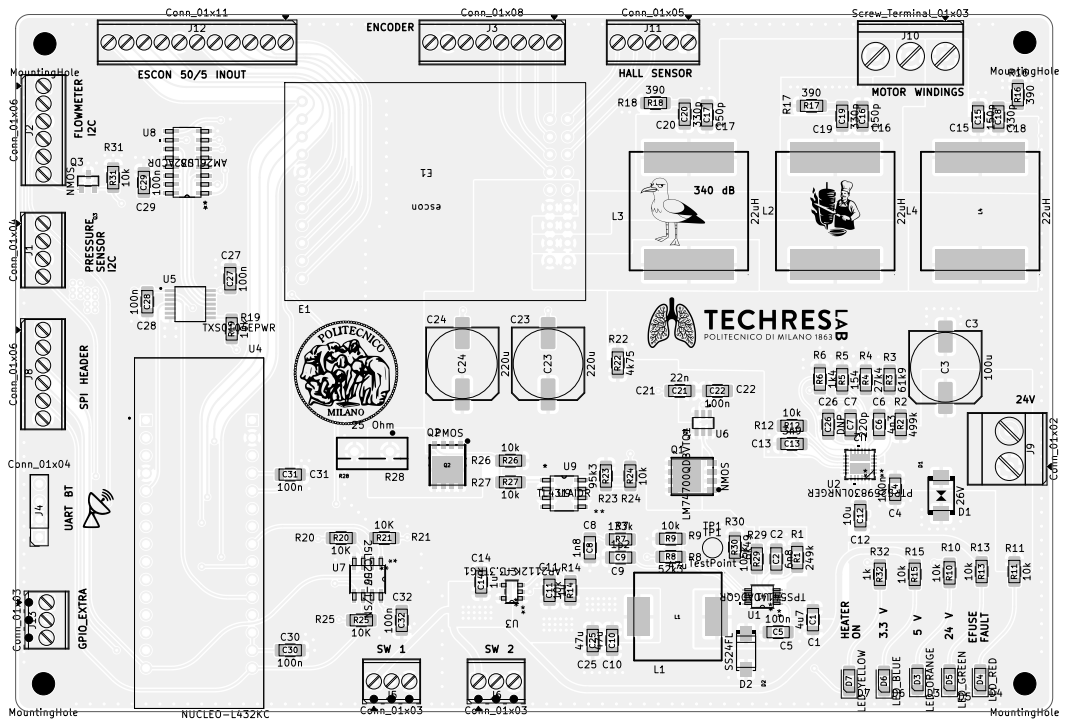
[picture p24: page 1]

Sheet: Black And White TOP
File: motherboard.kicad_pcb
Title:
KiCad E.D.A. 10.0.1

# SCL SCL 3.3V GND

# 3.3V 3.3V MISO MOSI SCK

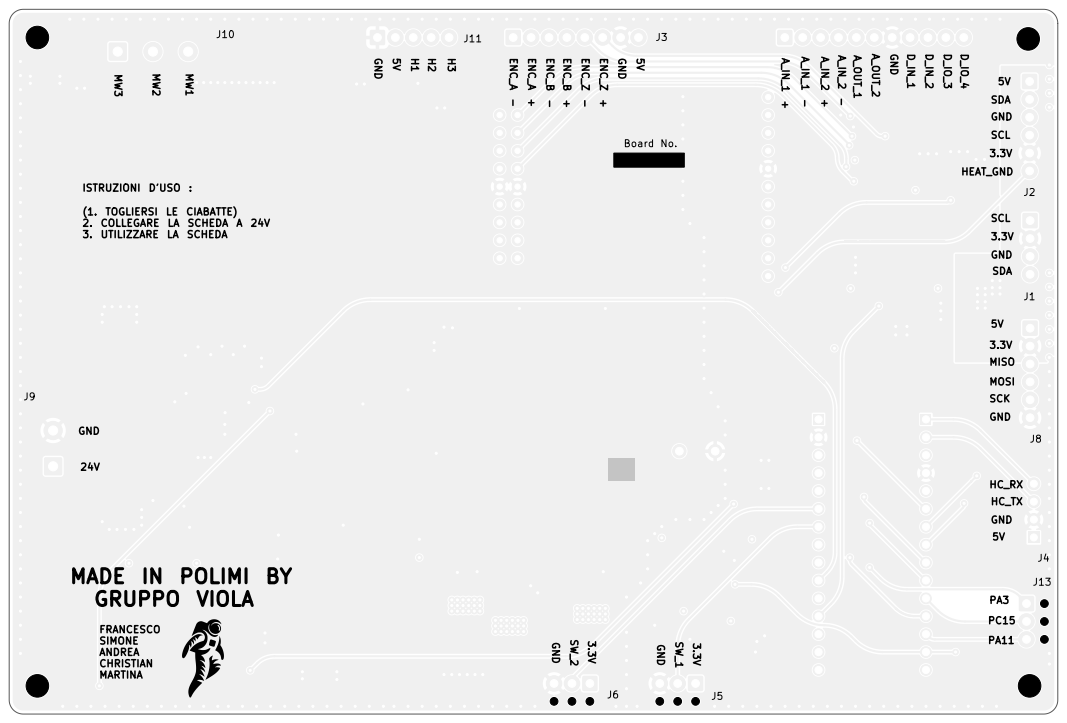
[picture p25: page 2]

MADE IN POLIMI BY
GRUPPO VIOLA

Board2Pdf: Black And White BOT - Page 2/2

Sheet: Black And White BOT
File: motherboard.kicad_pcb
Title:
KiCad E.D.A. 10.0.1

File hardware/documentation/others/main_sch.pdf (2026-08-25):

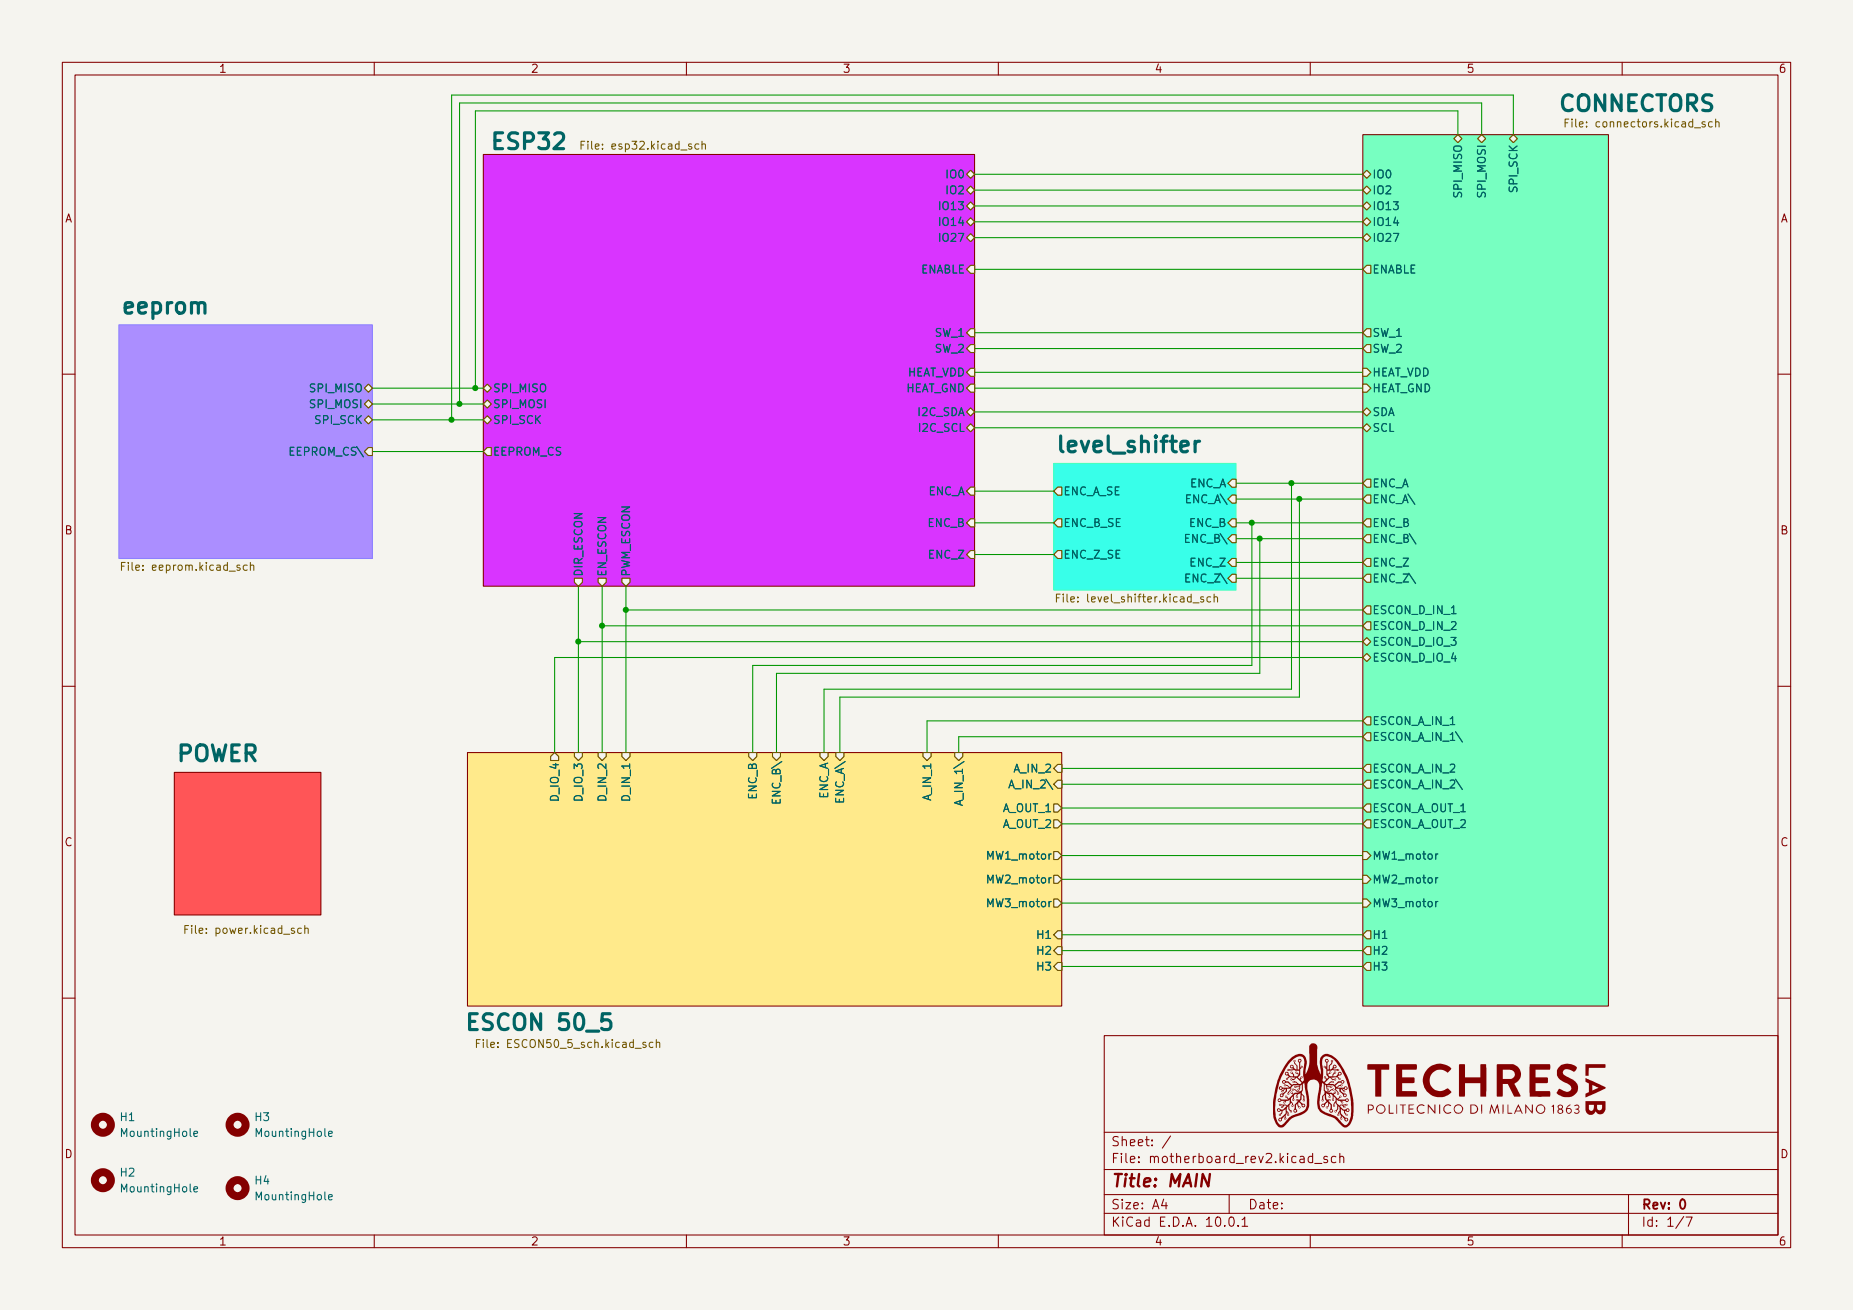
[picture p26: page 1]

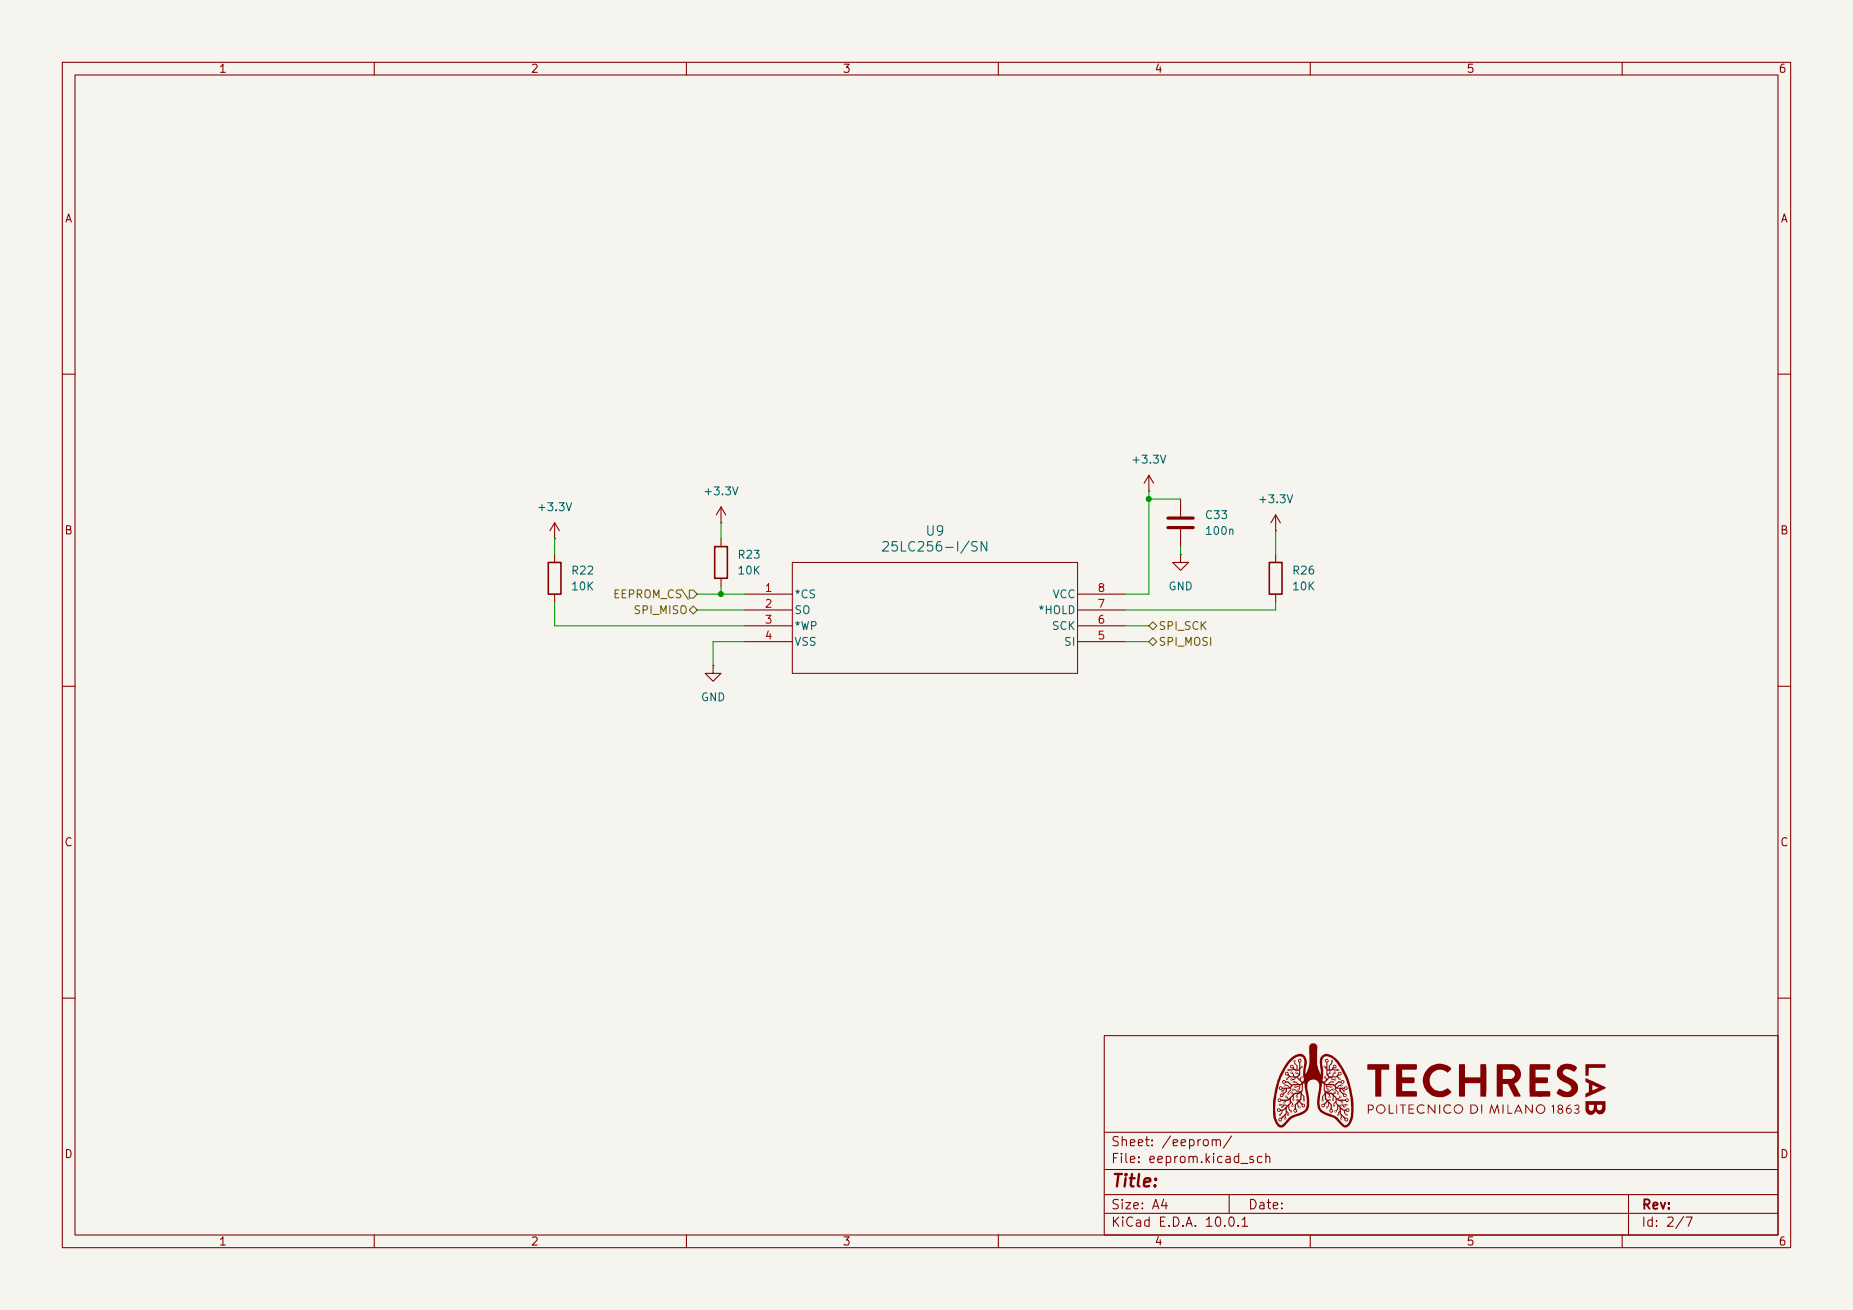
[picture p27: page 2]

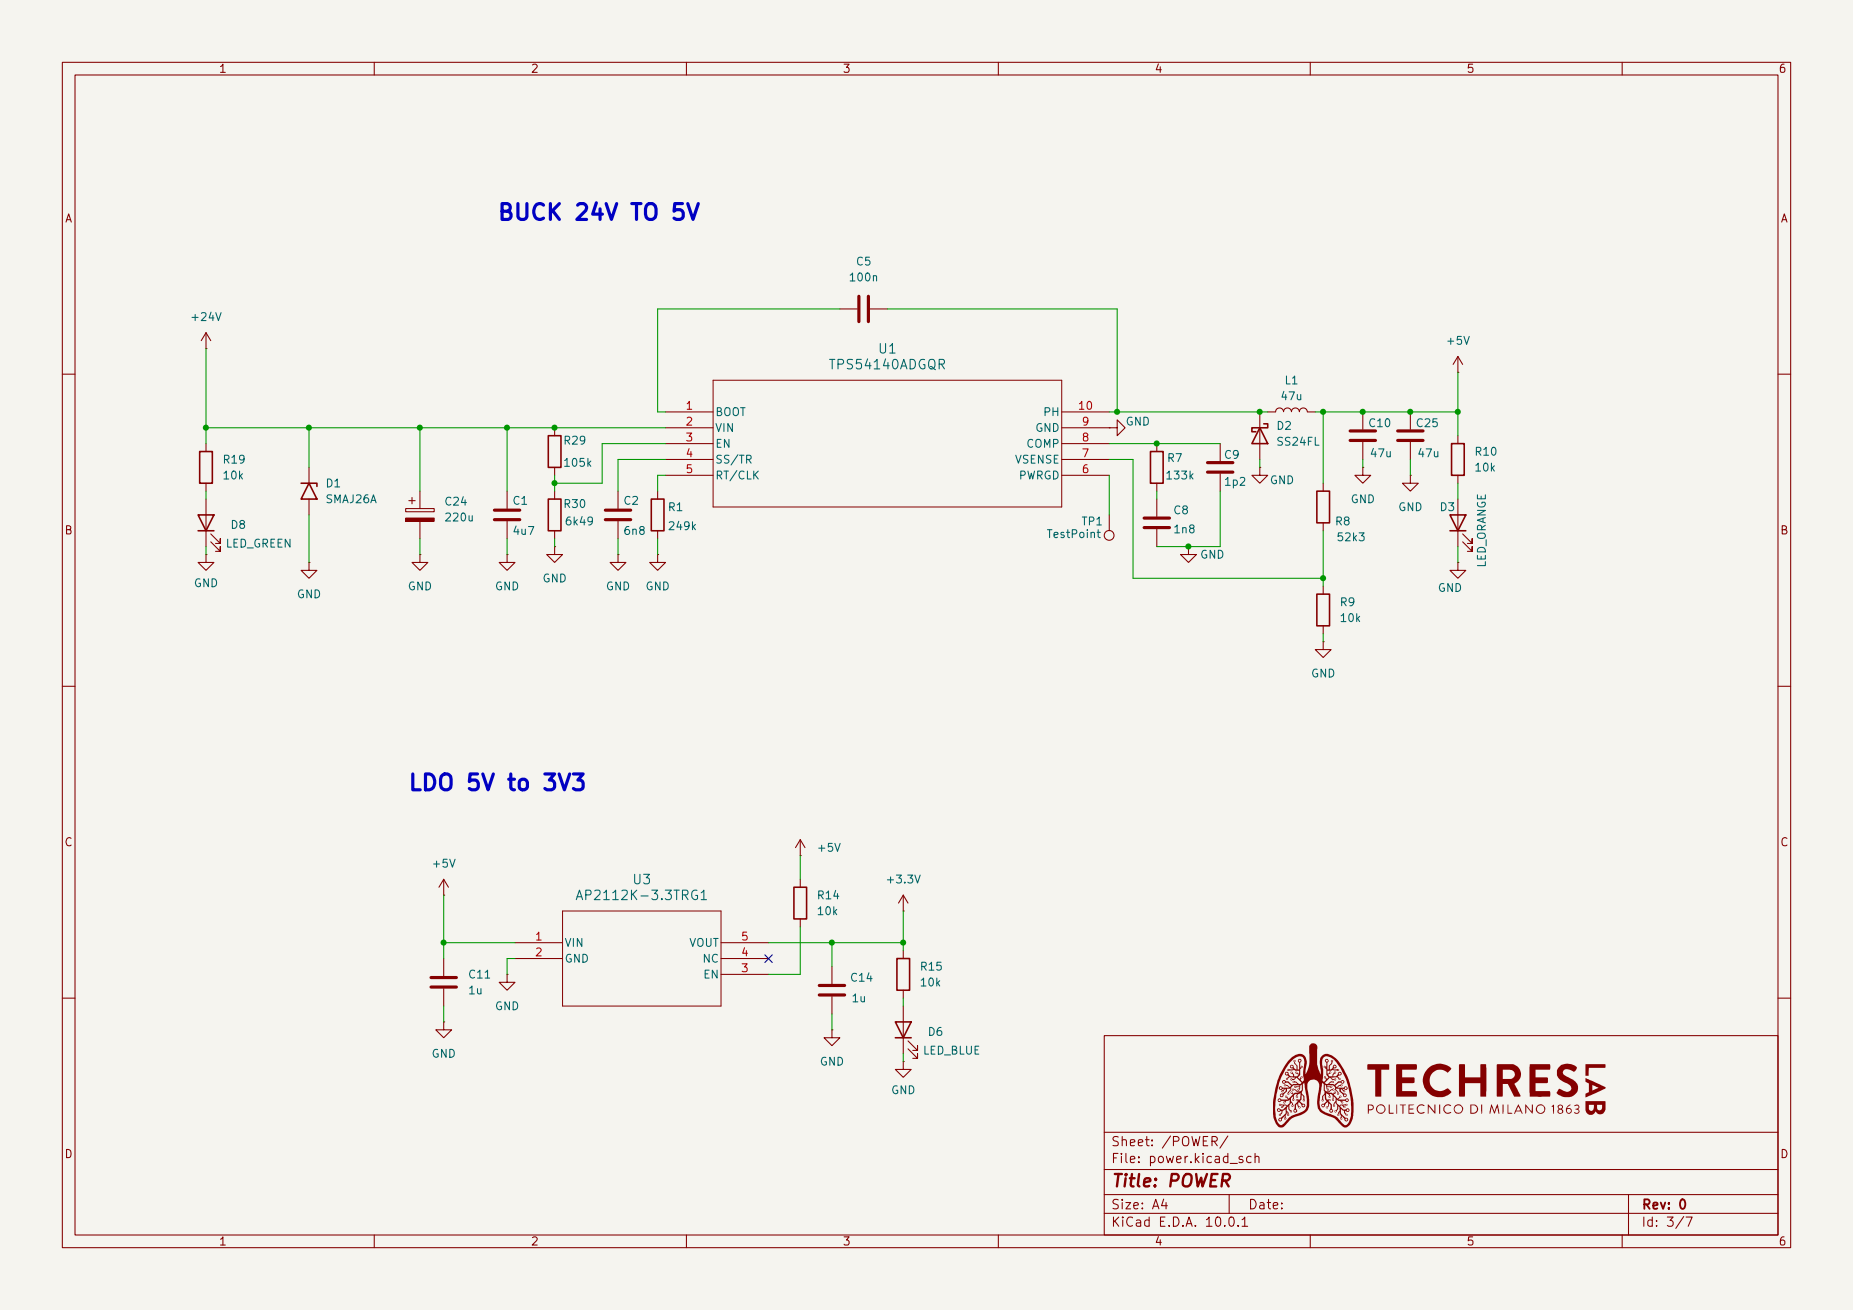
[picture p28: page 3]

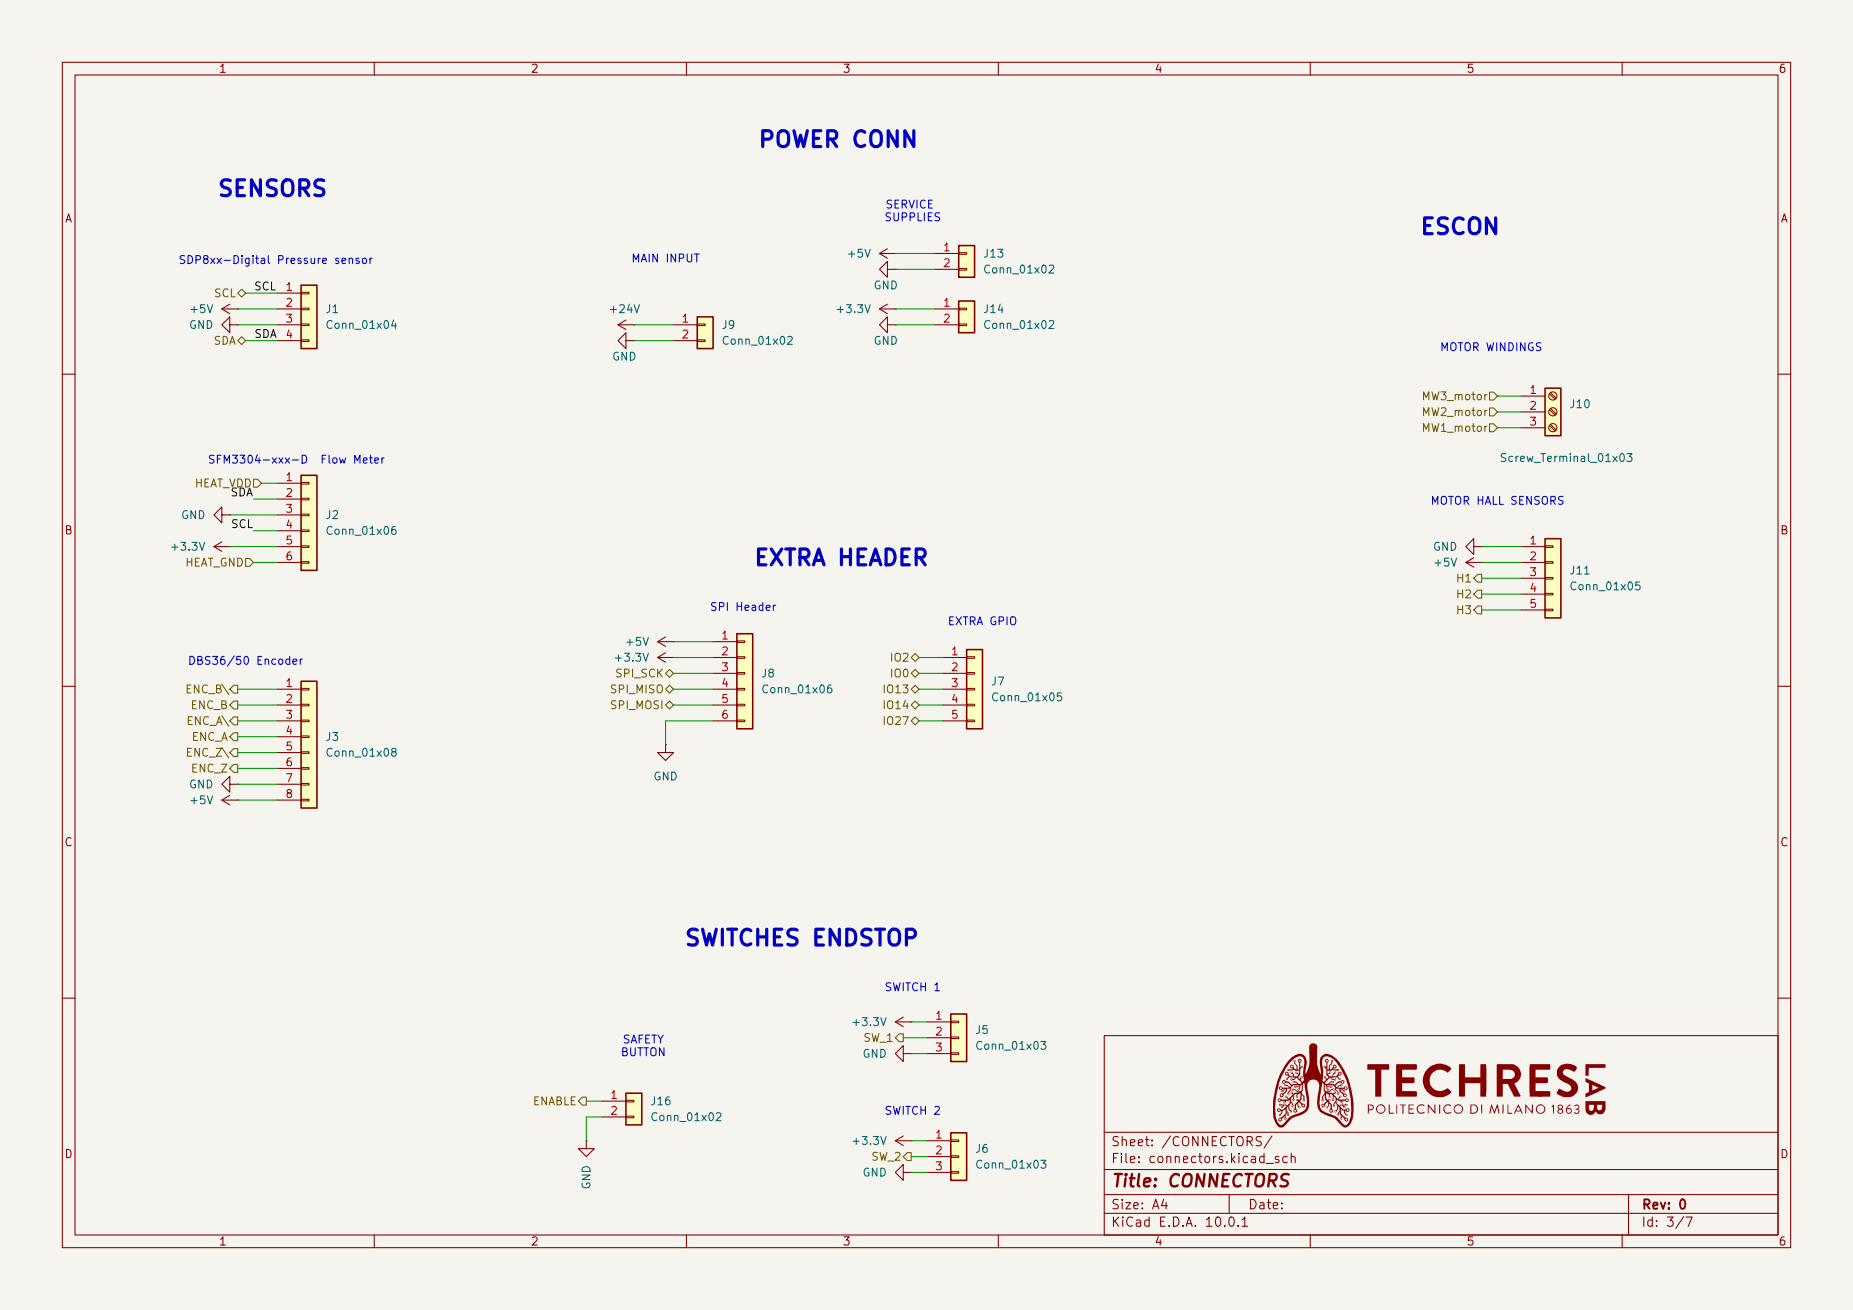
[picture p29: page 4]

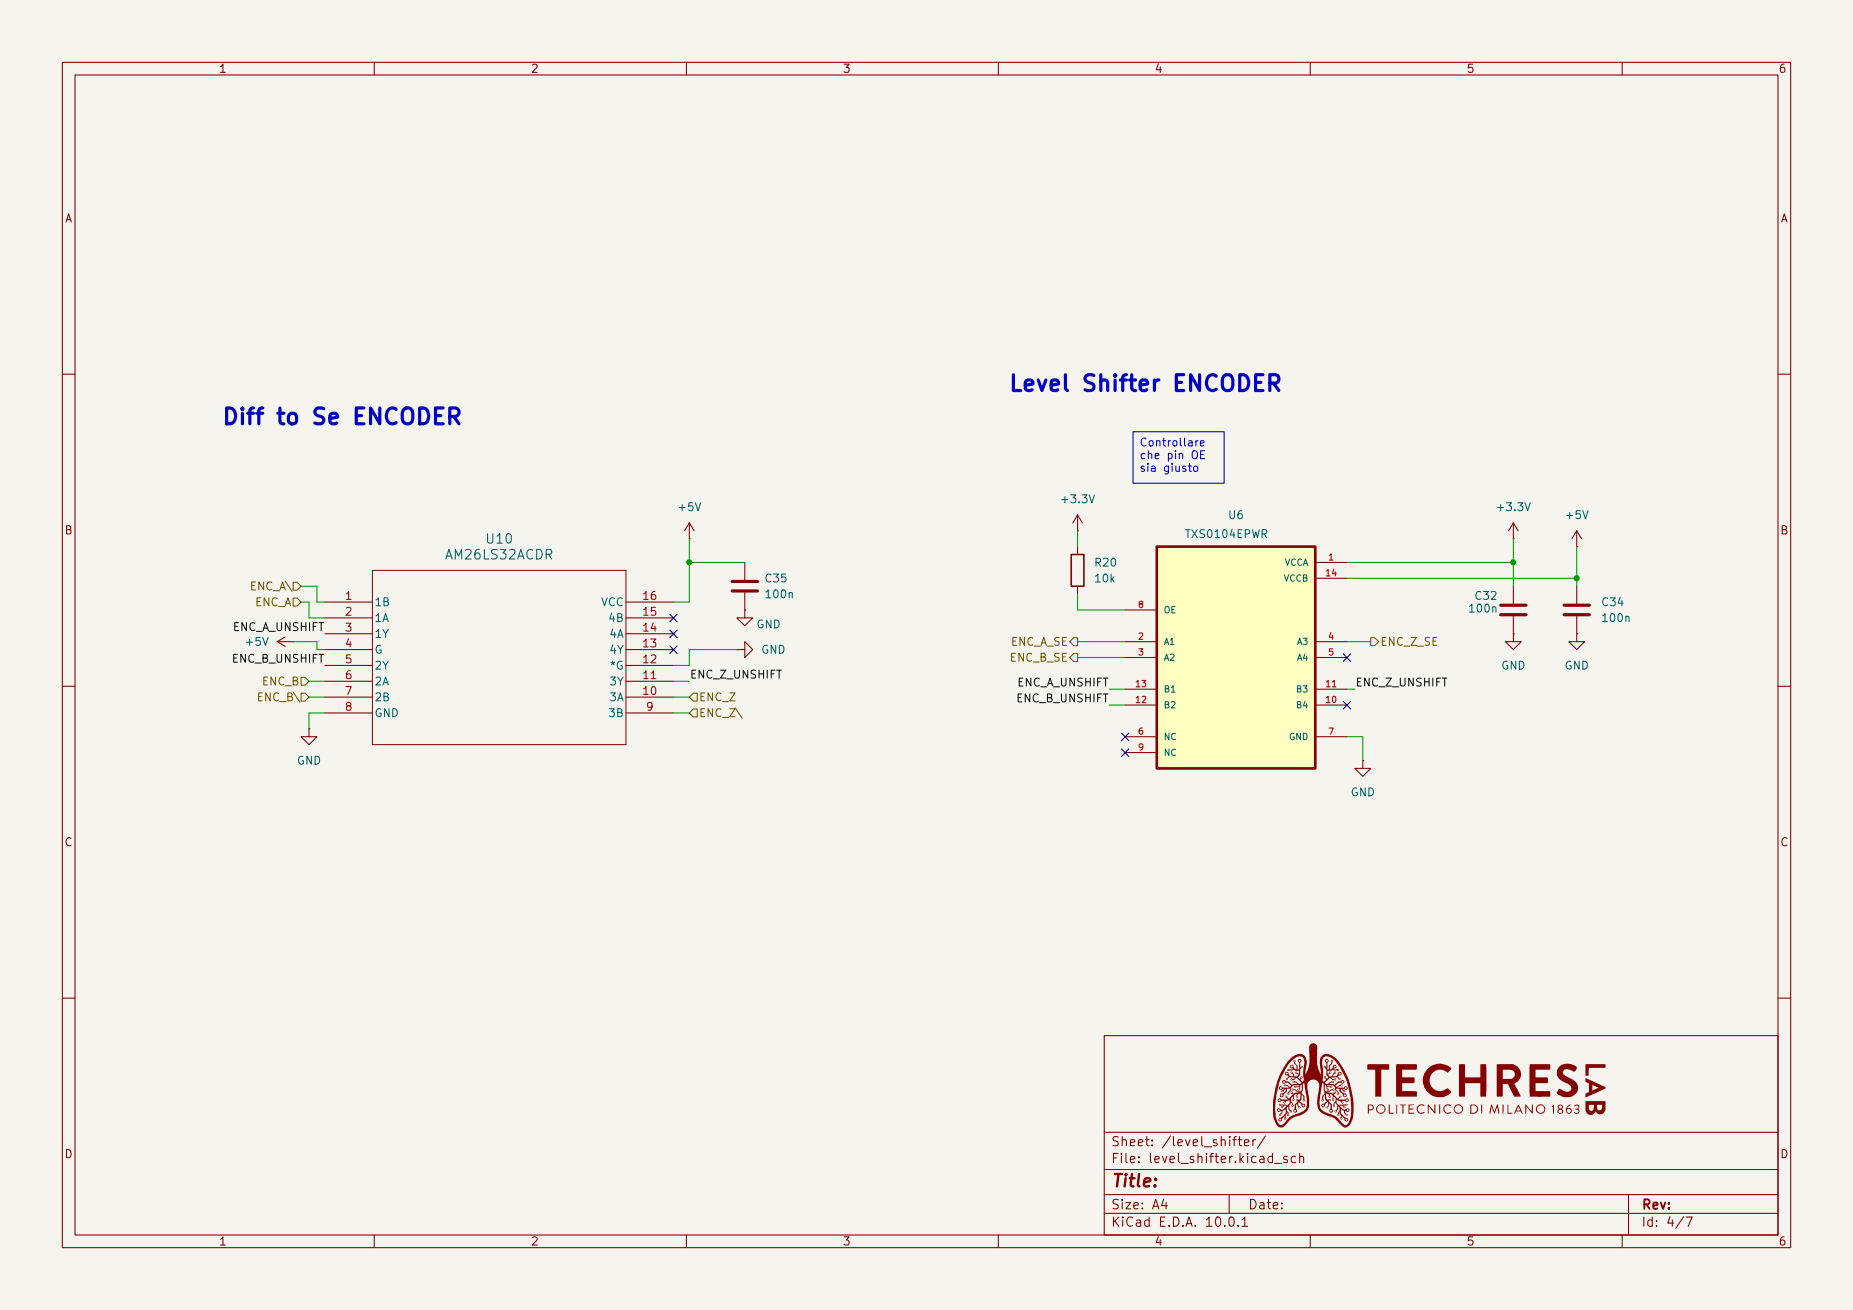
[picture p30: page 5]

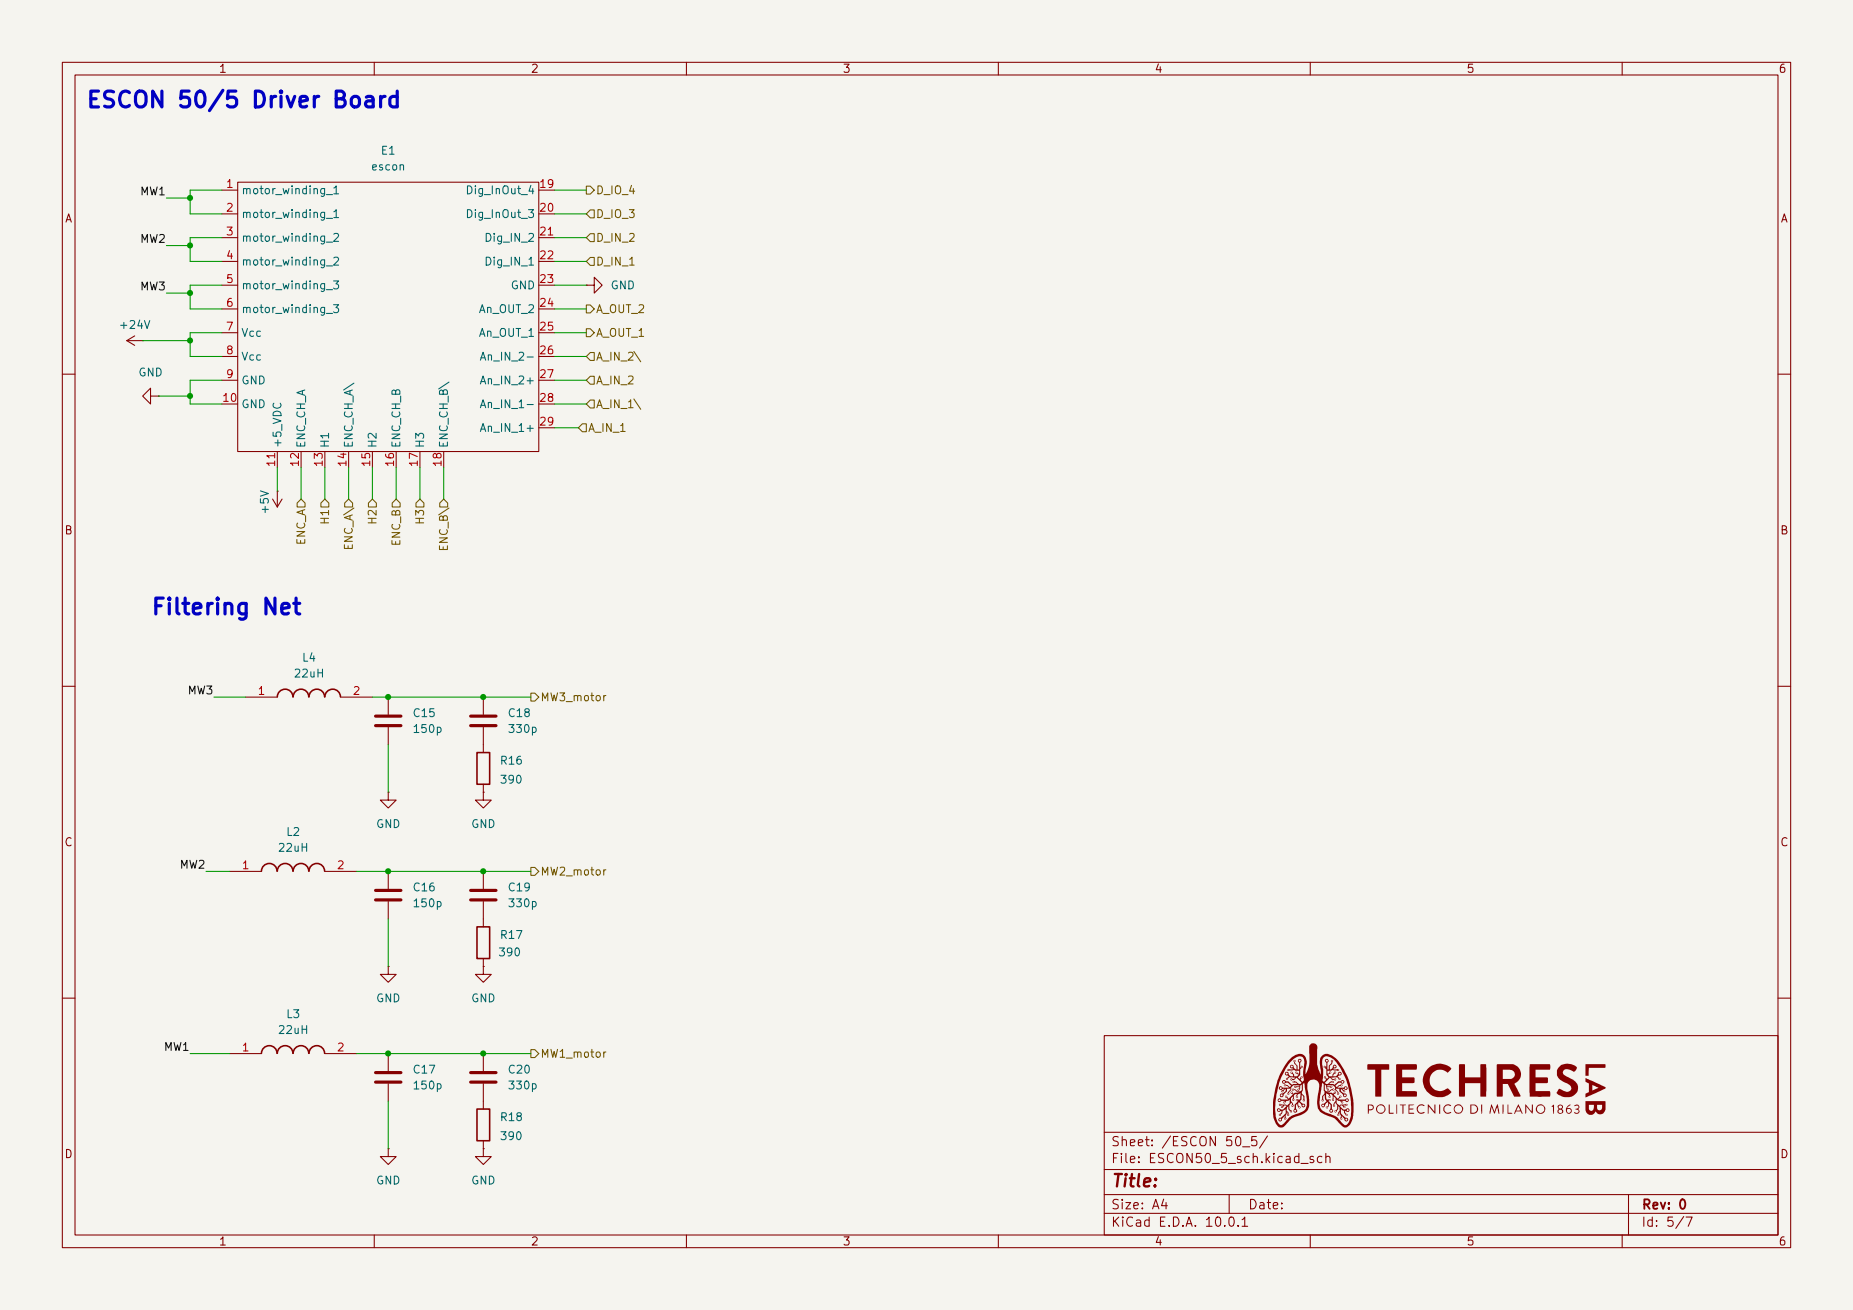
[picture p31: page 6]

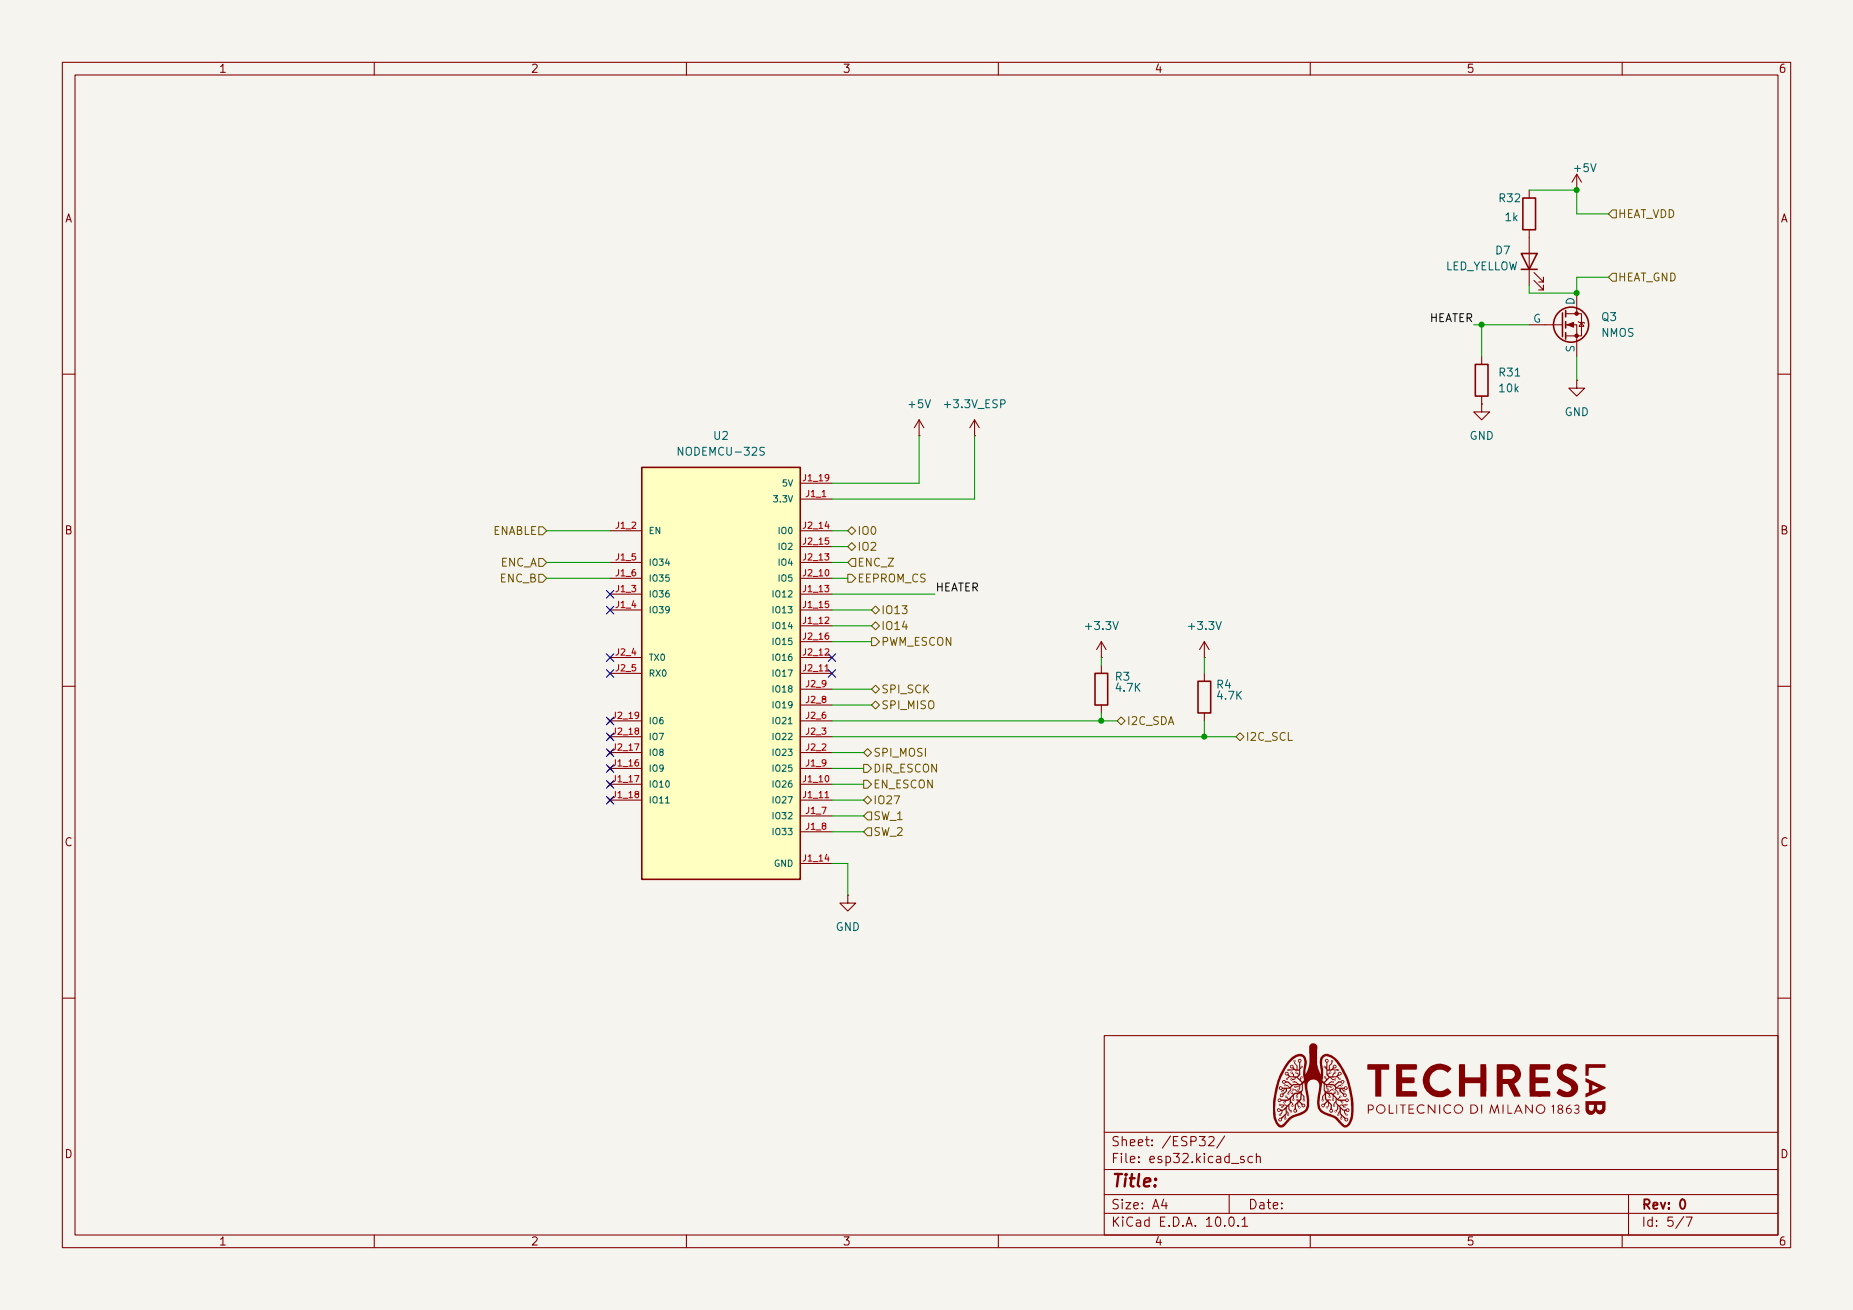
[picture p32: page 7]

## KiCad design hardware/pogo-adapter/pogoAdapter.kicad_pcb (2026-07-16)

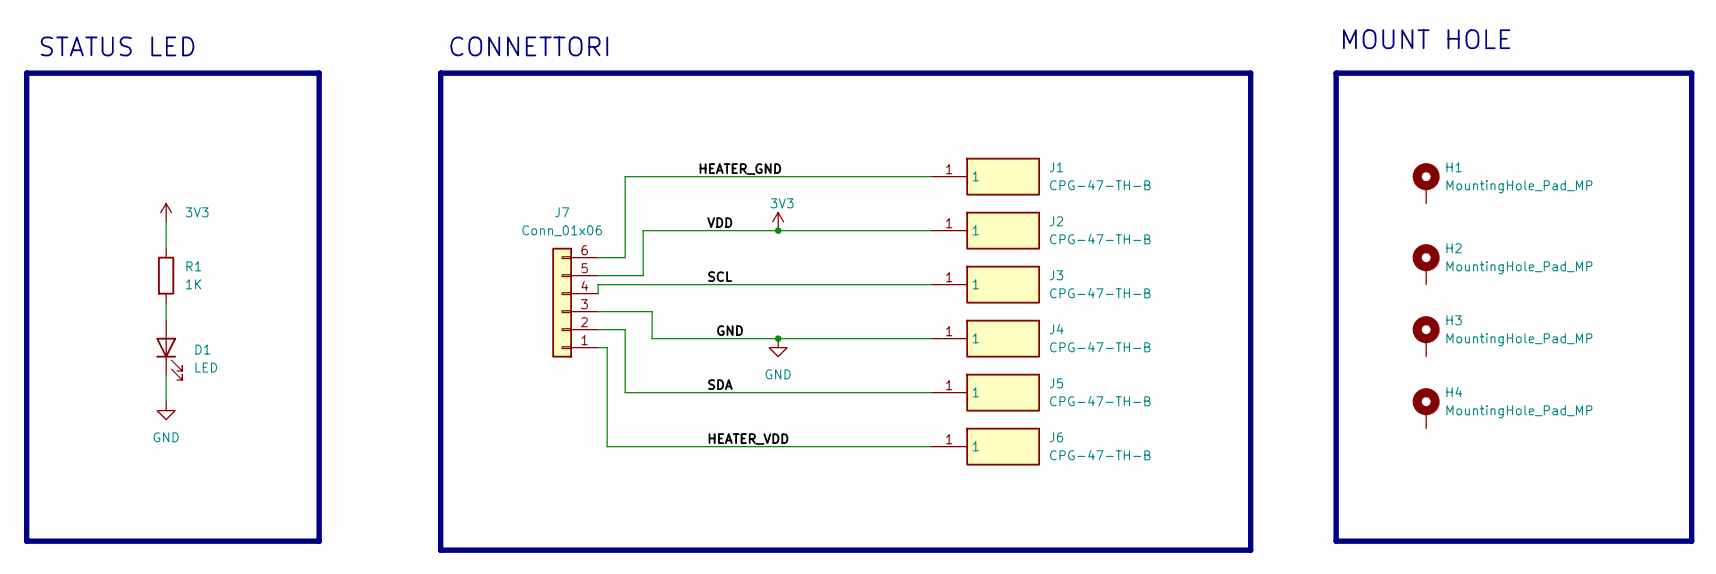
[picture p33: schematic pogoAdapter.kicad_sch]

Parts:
D1: LED; LED_1206_3216Metric_Pad1.42x1.75mm_HandSolder
H1, H2, H3, H4: MountingHole_Pad_MP; mountHole_1.8mm
J1, J2, J3, J4, J5, J6: CPG-47-TH-B; CPG47THB; Manufacturer_Part_Number CPG-47-TH-B
J7: Conn_01x06; TerminalBlock_Phoenix_MPT-0,5-6-2.54_1x06_P2.54mm_Horizontal
R1: 1K; R_1206_3216Metric_Pad1.30x1.75mm_HandSolder

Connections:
3V3: J2.1 (1_1), J7.5, R1.1
/HEATER_GND: J1.1 (1_1), J7.6
/HEATER_VDD: J6.1 (1_1), J7.1
/SCL: J3.1 (1_1), J7.4
/SDA: J5.1 (1_1), J7.2
GND: D1.1 (K), H1.1, H2.1, H3.1, H4.1, J4.1 (1_1), J7.3
unnamed: D1.2 (A), R1.2

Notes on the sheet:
MOUNT HOLE
CONNETTORI
STATUS LED

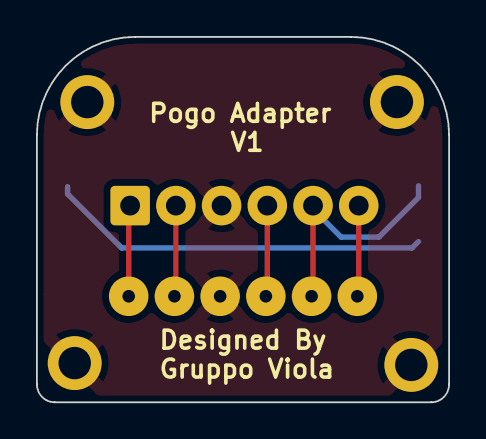
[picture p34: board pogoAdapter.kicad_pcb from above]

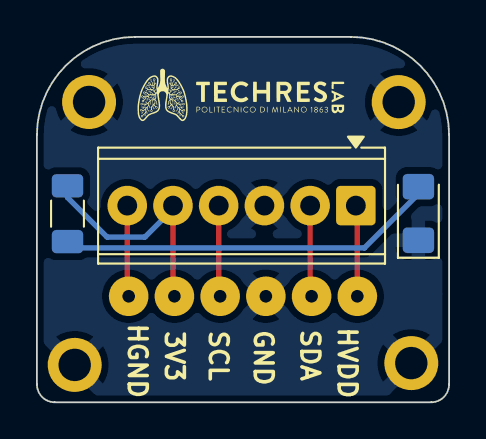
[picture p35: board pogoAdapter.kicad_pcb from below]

Board: 2 copper layers, 22.9 x 20.3 mm, 13 parts (3 on the bottom side), 7 nets.

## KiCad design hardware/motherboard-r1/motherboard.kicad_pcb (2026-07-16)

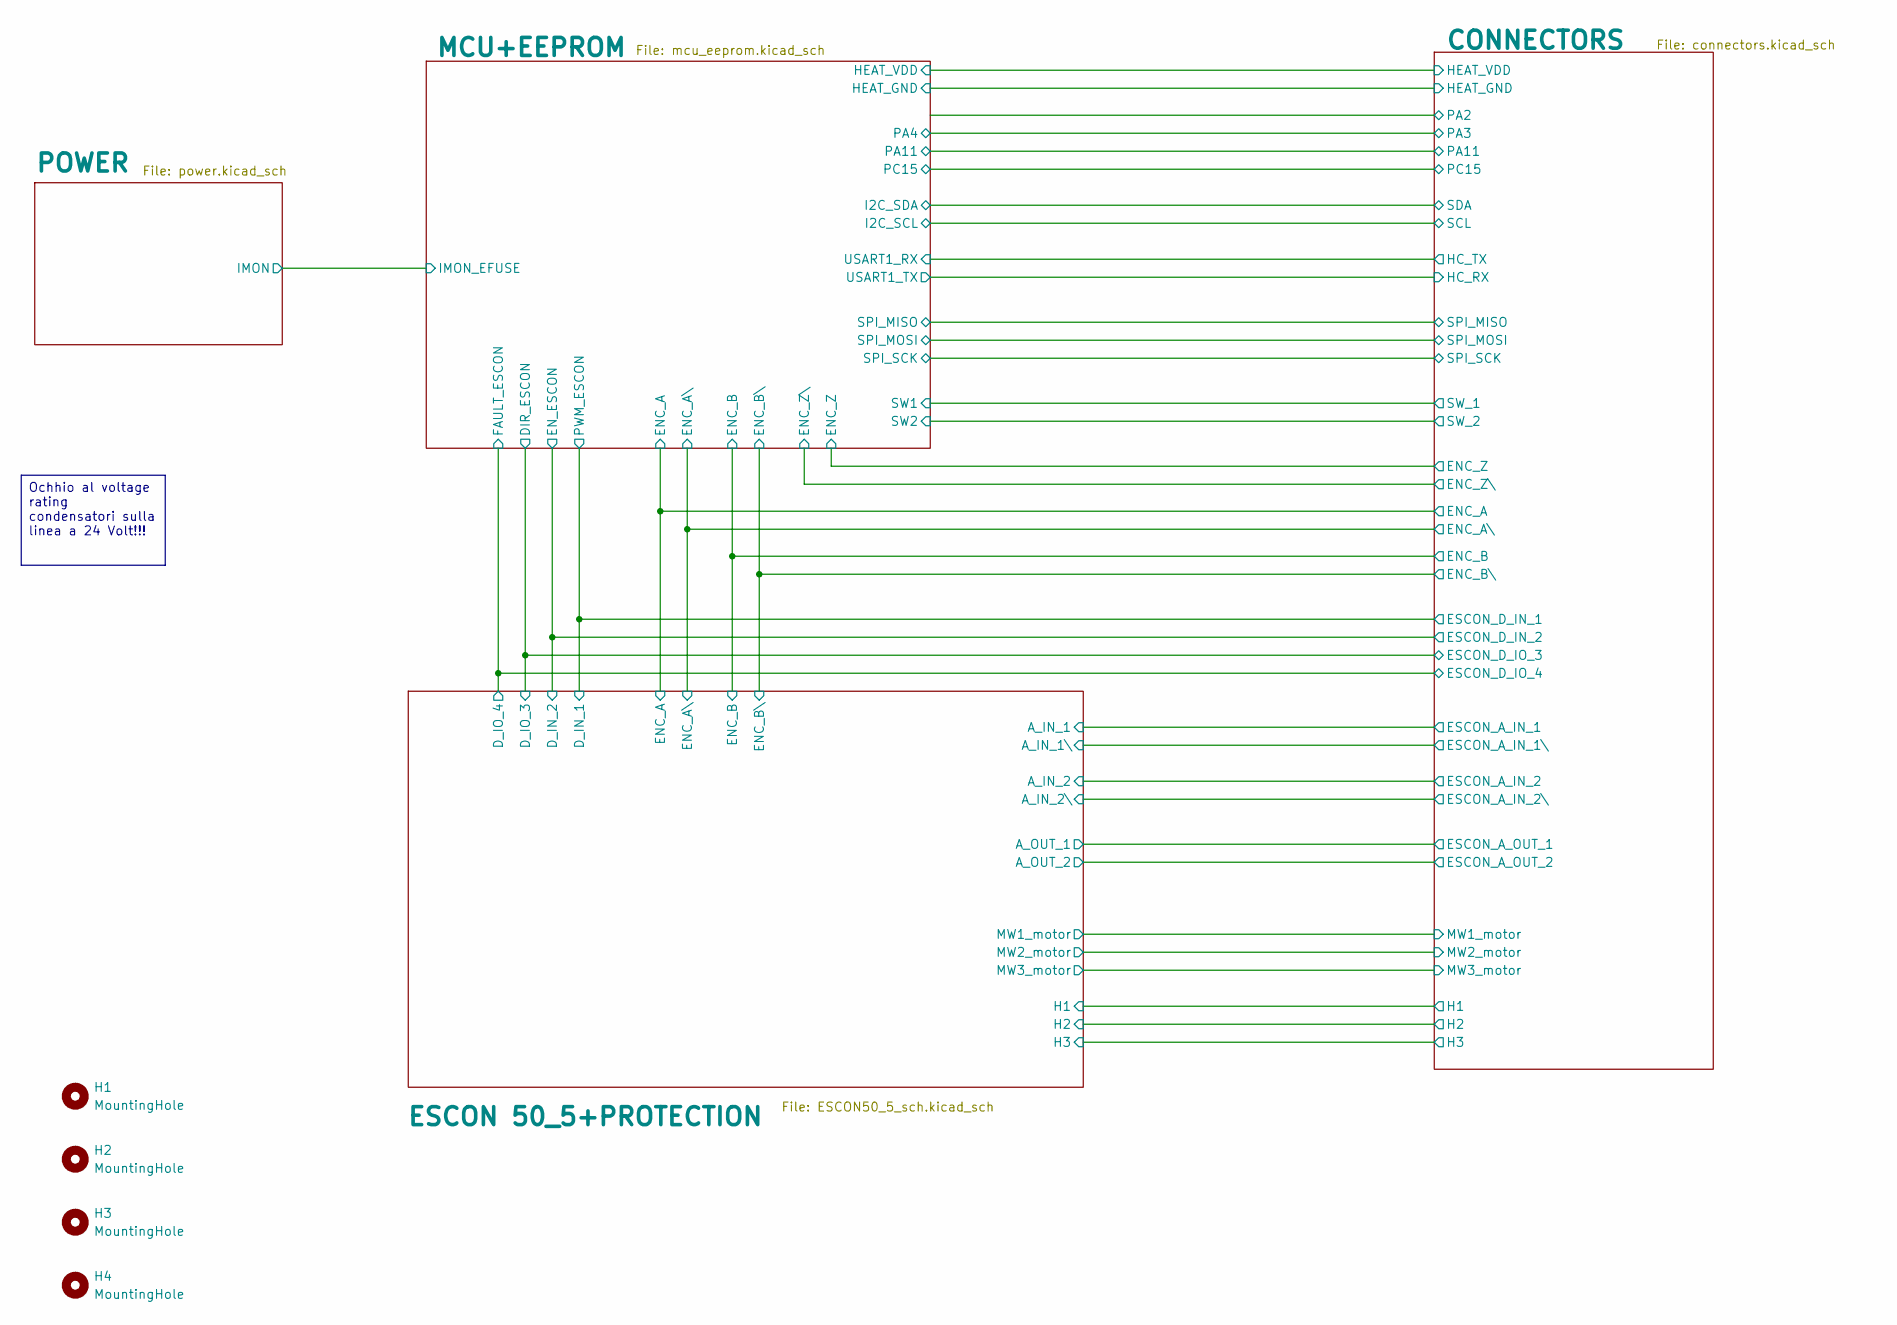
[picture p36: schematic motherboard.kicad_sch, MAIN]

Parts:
H1, H2, H3, H4: MountingHole; MountingHole_3.2mm_M3

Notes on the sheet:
Ochhio al voltage rating condensatori sulla linea a 24 Volt!!!

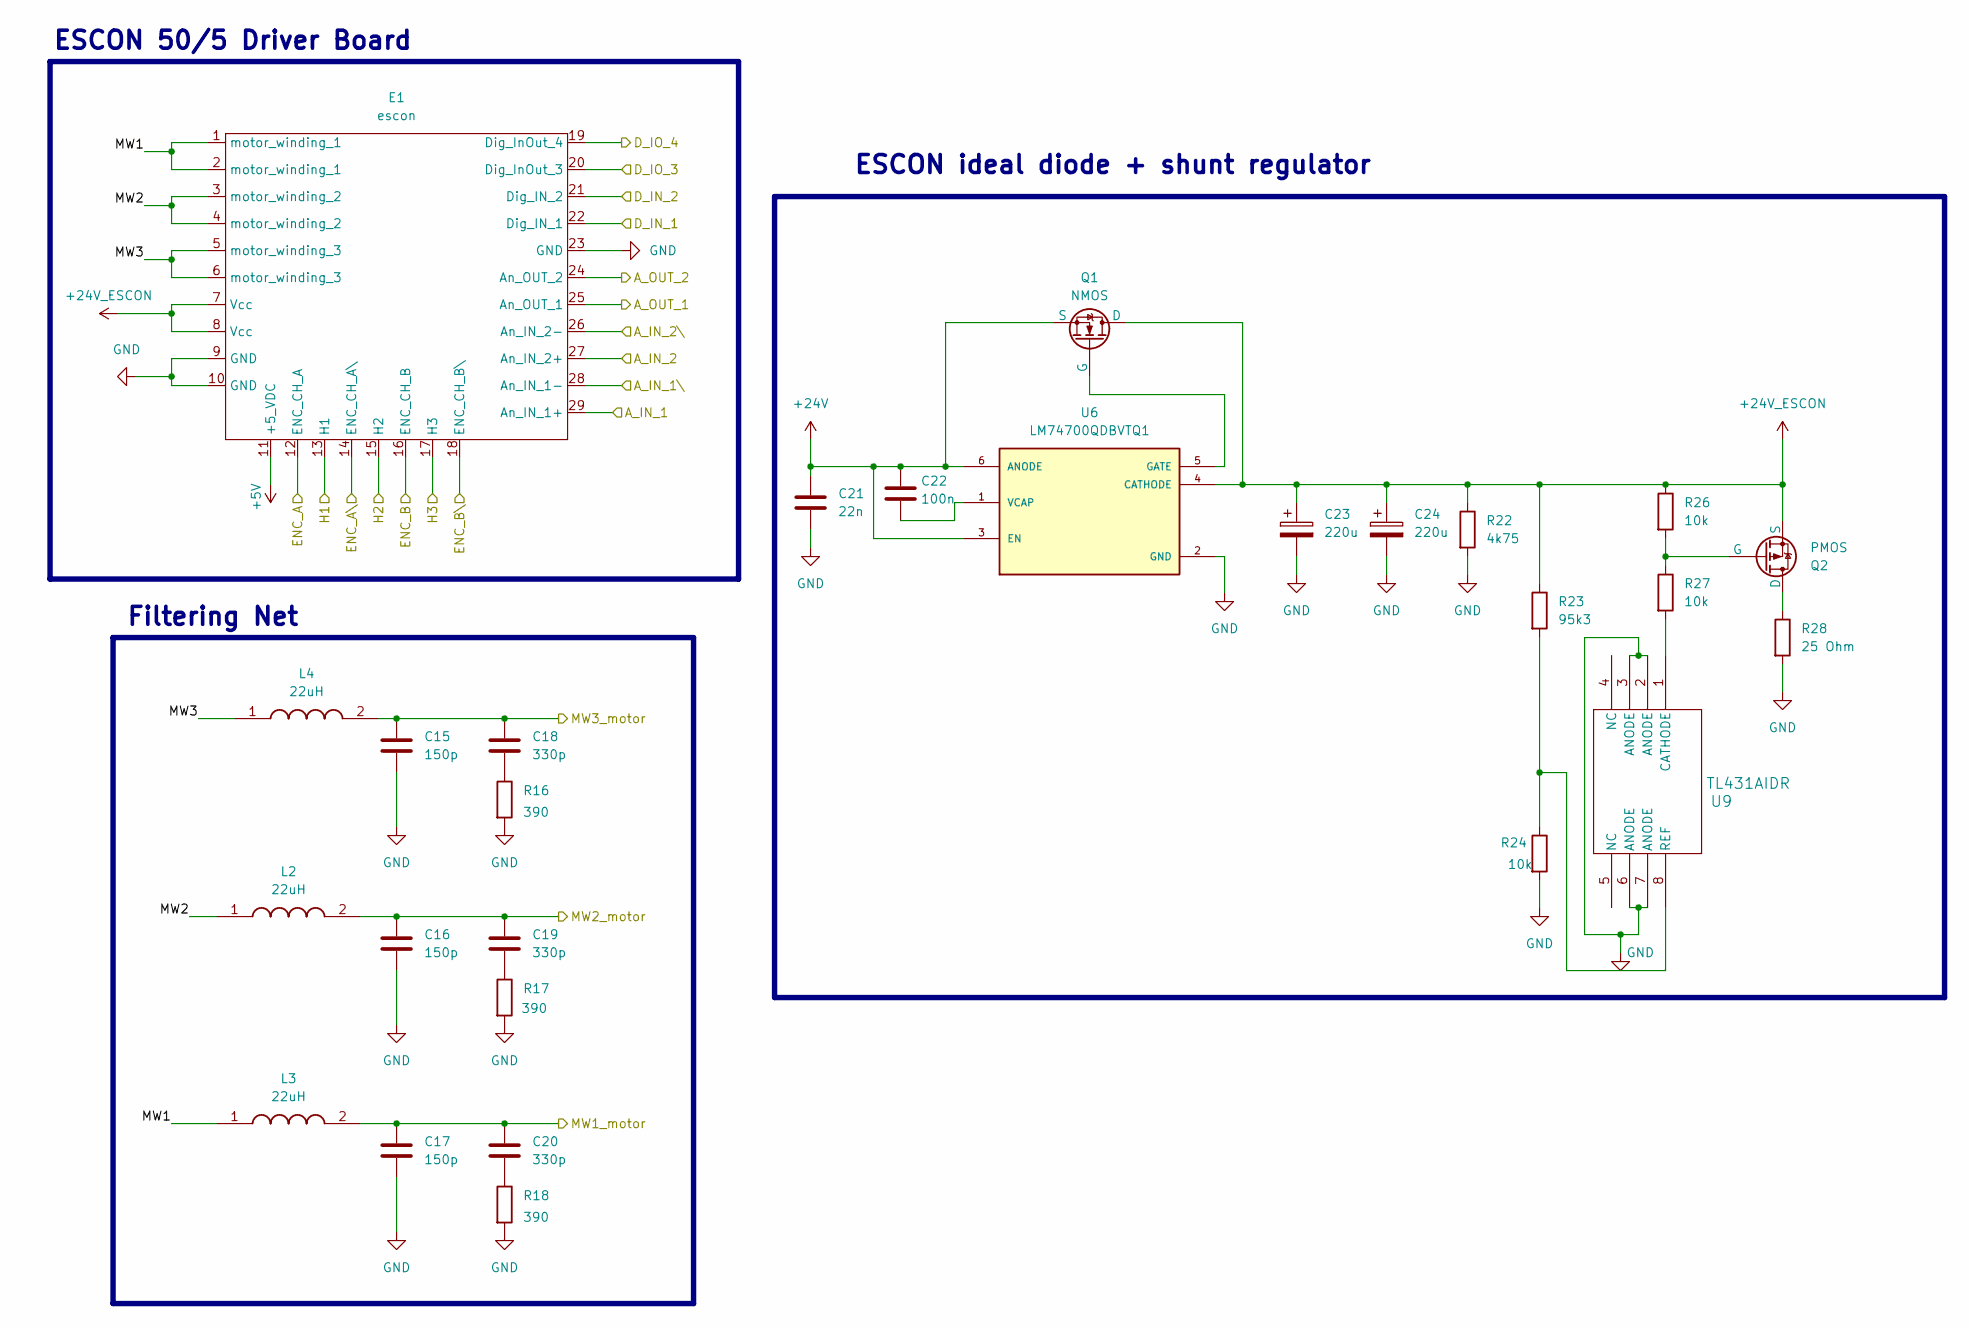
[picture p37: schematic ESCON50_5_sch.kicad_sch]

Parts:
C15, C16, C17: 150p; C_1206_3216Metric_Pad1.33x1.80mm_HandSolder; LCSC Part # C282831
C18, C19, C20: 330p; C_1206_3216Metric_Pad1.33x1.80mm_HandSolder; LCSC Part # C106055
C21: 22n; C_1206_3216Metric_Pad1.33x1.80mm_HandSolder
C22: 100n; C_1206_3216Metric_Pad1.33x1.80mm_HandSolder
C23, C24: 220u; C_Elec_10x10.2
E1: escon; escon_vero
L2, L3, L4: 22uH; IND-SMD_L17.0-W17.0_YSPIA1770-100M; LCSC Part # C5122901
Q1: NMOS; PG-TDSON-8_L5.0-W6.0-P1.27-BL-EP
Q2: PMOS; DFN-8_L5.7-W4.9-P1.27-LS6.1-BL
R16, R17, R18: 390; R_1206_3216Metric_Pad1.30x1.75mm_HandSolder; LCSC Part # C4491
R22: 4k75; R_1206_3216Metric_Pad1.30x1.75mm_HandSolder
R23: 95k3; R_1206_3216Metric_Pad1.30x1.75mm_HandSolder
R24, R26, R27: 10k; R_1206_3216Metric_Pad1.30x1.75mm_HandSolder
R28: 25 Ohm; TO-220-2_L10.1-W4.5-P5.08-L
U6: LM74700QDBVTQ1; SOT95P280X145-6N; PARTREV F
U9: TL431AIDR; D8

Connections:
+5V: E1.11 (+5_VDC); also elsewhere on the board
+24V: C21.1, C22.1, Q1.3 (S), U6.3 (EN), U6.6 (ANODE); also elsewhere on the board
+24V_ESCON: C23.1, C24.1, E1.7 (Vcc), E1.8 (Vcc), Q1.1 (D), Q2.3 (S), R22.1, R23.1, R26.1, U6.4 (CATHODE)
/CONNECTORS/ENC_A: E1.12 (ENC_CH_A); also elsewhere on the board
/CONNECTORS/ENC_A\: E1.14 (ENC_CH_A\); also elsewhere on the board
/CONNECTORS/ENC_B: E1.16 (ENC_CH_B); also elsewhere on the board
/CONNECTORS/ENC_B\: E1.18 (ENC_CH_B\); also elsewhere on the board
/CONNECTORS/ESCON_A_IN_1: E1.29 (An_IN_1+); also elsewhere on the board
/CONNECTORS/ESCON_A_IN_1\: E1.28 (An_IN_1-); also elsewhere on the board
/CONNECTORS/ESCON_A_IN_2: E1.27 (An_IN_2+); also elsewhere on the board
/CONNECTORS/ESCON_A_IN_2\: E1.26 (An_IN_2-); also elsewhere on the board
/CONNECTORS/ESCON_A_OUT_1: E1.25 (An_OUT_1); also elsewhere on the board
/CONNECTORS/ESCON_A_OUT_2: E1.24 (An_OUT_2); also elsewhere on the board
/CONNECTORS/ESCON_D_IN_1: E1.22 (Dig_IN_1); also elsewhere on the board
/CONNECTORS/ESCON_D_IN_2: E1.21 (Dig_IN_2); also elsewhere on the board
/CONNECTORS/ESCON_D_IO_3: E1.20 (Dig_InOut_3); also elsewhere on the board
/CONNECTORS/ESCON_D_IO_4: E1.19 (Dig_InOut_4); also elsewhere on the board
/CONNECTORS/H1: E1.13 (H1); also elsewhere on the board
/CONNECTORS/H2: E1.15 (H2); also elsewhere on the board
/CONNECTORS/H3: E1.17 (H3); also elsewhere on the board
/CONNECTORS/MW1_motor: C17.1, C20.1, L3.2; also elsewhere on the board
/CONNECTORS/MW2_motor: C16.1, C19.1, L2.2; also elsewhere on the board
/CONNECTORS/MW3_motor: C15.1, C18.1, L4.2; also elsewhere on the board
/ESCON 50_5+PROTECTION/MW1: E1.1 (motor_winding_1), E1.2 (motor_winding_1), L3.1
/ESCON 50_5+PROTECTION/MW2: E1.3 (motor_winding_2), E1.4 (motor_winding_2), L2.1
/ESCON 50_5+PROTECTION/MW3: E1.5 (motor_winding_3), E1.6 (motor_winding_3), L4.1
GND: C15.2, C16.2, C17.2, C21.2, C23.2, C24.2, E1.9 (GND), E1.10 (GND), E1.23 (GND), R16.2, R17.2, R18.2, R22.2, R24.2, R28.2, U6.2 (GND), U9.2 (ANODE), U9.3 (ANODE), U9.6 (ANODE), U9.7 (ANODE); also elsewhere on the board
unnamed: C18.2, R16.1
unnamed: C19.2, R17.1
unnamed: C20.2, R18.1
unnamed: Q1.2 (G), U6.5 (GATE)
unnamed: Q2.1 (D), R28.1
unnamed: Q2.2 (G), R26.2, R27.1
unnamed: C22.2, U6.1 (VCAP)
unnamed: R27.2, U9.1 (CATHODE)
unnamed: R23.2, R24.1, U9.8 (REF)

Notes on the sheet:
ESCON ideal diode + shunt regulator
Filtering Net
ESCON 50/5 Driver Board

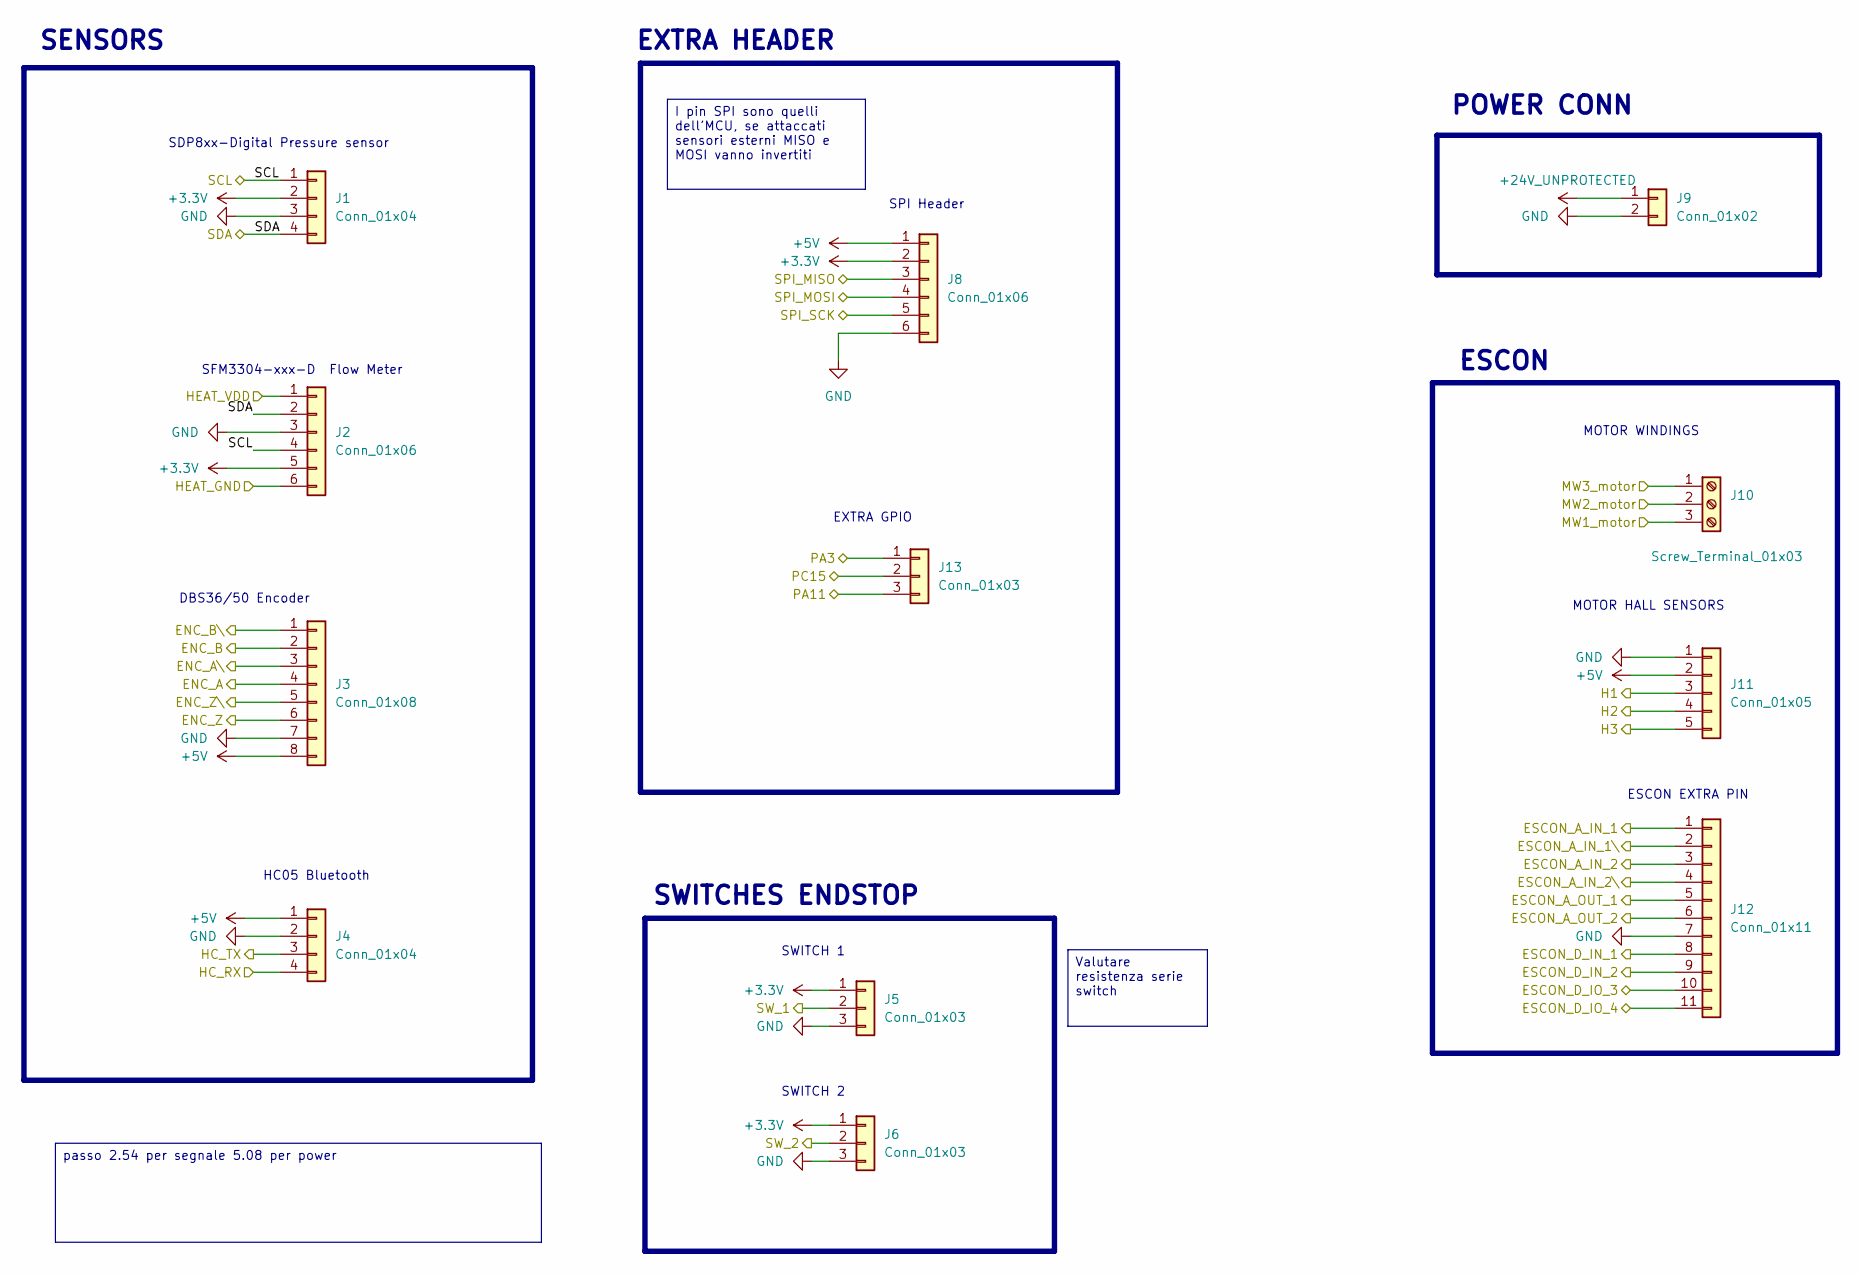
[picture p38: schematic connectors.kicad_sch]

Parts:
J1: Conn_01x04; TerminalBlock_Phoenix_MPT-0,5-4-2.54_1x04_P2.54mm_Horizontal
J2, J8: Conn_01x06; TerminalBlock_Phoenix_MPT-0,5-6-2.54_1x06_P2.54mm_Horizontal
J3: Conn_01x08; TerminalBlock_Phoenix_MPT-0,5-8-2.54_1x08_P2.54mm_Horizontal
J4: Conn_01x04; PinSocket_1x04_P2.54mm_Vertical
J5, J6, J13: Conn_01x03; TerminalBlock_Phoenix_MPT-0,5-3-2.54_1x03_P2.54mm_Horizontal
J9: Conn_01x02; TerminalBlock_Phoenix_MKDS-3-2-5.08_1x02_P5.08mm_Horizontal
J10: Screw_Terminal_01x03; TerminalBlock_Phoenix_PT-1,5-3-5.0-H_1x03_P5.00mm_Horizontal
J11: Conn_01x05; TerminalBlock_Phoenix_MPT-0,5-5-2.54_1x05_P2.54mm_Horizontal
J12: Conn_01x11; TerminalBlock_Phoenix_MPT-0,5-11-2.54_1x11_P2.54mm_Horizont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

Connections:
+3.3V: J1.2, J2.5, J5.1, J6.1, J8.2; also elsewhere on the board
+5V: J2.1, J3.8, J4.1, J8.1, J11.2; also elsewhere on the board
+24V_UNPROTECTED: J9.1; also elsewhere on the board
/CONNECTORS/ENC_A: J3.4; also elsewhere on the board
/CONNECTORS/ENC_A\: J3.3; also elsewhere on the board
/CONNECTORS/ENC_B: J3.2; also elsewhere on the board
/CONNECTORS/ENC_B\: J3.1; also elsewhere on the board
/CONNECTORS/ENC_Z: J3.6; also elsewhere on the board
/CONNECTORS/ENC_Z\: J3.5; also elsewhere on the board
/CONNECTORS/ESCON_A_IN_1: J12.1; also elsewhere on the board
/CONNECTORS/ESCON_A_IN_1\: J12.2; also elsewhere on the board
/CONNECTORS/ESCON_A_IN_2: J12.3; also elsewhere on the board
/CONNECTORS/ESCON_A_IN_2\: J12.4; also elsewhere on the board
/CONNECTORS/ESCON_A_OUT_1: J12.5; also elsewhere on the board
/CONNECTORS/ESCON_A_OUT_2: J12.6; also elsewhere on the board
/CONNECTORS/ESCON_D_IN_1: J12.8; also elsewhere on the board
/CONNECTORS/ESCON_D_IN_2: J12.9; also elsewhere on the board
/CONNECTORS/ESCON_D_IO_3: J12.10; also elsewhere on the board
/CONNECTORS/ESCON_D_IO_4: J12.11; also elsewhere on the board
/CONNECTORS/H1: J11.3; also elsewhere on the board
/CONNECTORS/H2: J11.4; also elsewhere on the board
/CONNECTORS/H3: J11.5; also elsewhere on the board
/CONNECTORS/HC_RX: J4.4; also elsewhere on the board
/CONNECTORS/HC_TX: J4.3; also elsewhere on the board
/CONNECTORS/HEAT_GND: J2.6; also elsewhere on the board
/CONNECTORS/MW1_motor: J10.3; also elsewhere on the board
/CONNECTORS/MW2_motor: J10.2; also elsewhere on the board
/CONNECTORS/MW3_motor: J10.1; also elsewhere on the board
/CONNECTORS/PA3: J13.1; also elsewhere on the board
/CONNECTORS/PA11: J13.3; also elsewhere on the board
/CONNECTORS/PC15: J13.2; also elsewhere on the board
/CONNECTORS/SCL: J1.1, J2.4; also elsewhere on the board
/CONNECTORS/SDA: J1.4, J2.2; also elsewhere on the board
/CONNECTORS/SW_1: J5.2; also elsewhere on the board
/CONNECTORS/SW_2: J6.2; also elsewhere on the board
/MCU+EEPROM/SPI_MISO: J8.3; also elsewhere on the board
/MCU+EEPROM/SPI_MOSI: J8.4; also elsewhere on the board
/MCU+EEPROM/SPI_SCK: J8.5; also elsewhere on the board
GND: J1.3, J2.3, J3.7, J4.2, J5.3, J6.3, J8.6, J9.2, J11.1, J12.7; also elsewhere on the board

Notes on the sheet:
SWITCH 2
MOTOR WINDINGS
SDP8xx-Digital Pressure sensor
DBS36/50 Encoder
SWITCHES ENDSTOP
SENSORS
EXTRA HEADER
SWITCH 1
ESCON EXTRA PIN
SPI Header
ESCON
SFM3304-xxx-D Flow Meter
MOTOR HALL SENSORS
HC05 Bluetooth
POWER CONN
EXTRA GPIO
Valutare resistenza serie switch
I pin SPI sono quelli dell'MCU, se attaccati sensori esterni MISO e MOSI vanno invertiti
passo 2.54 per segnale 5.08 per power

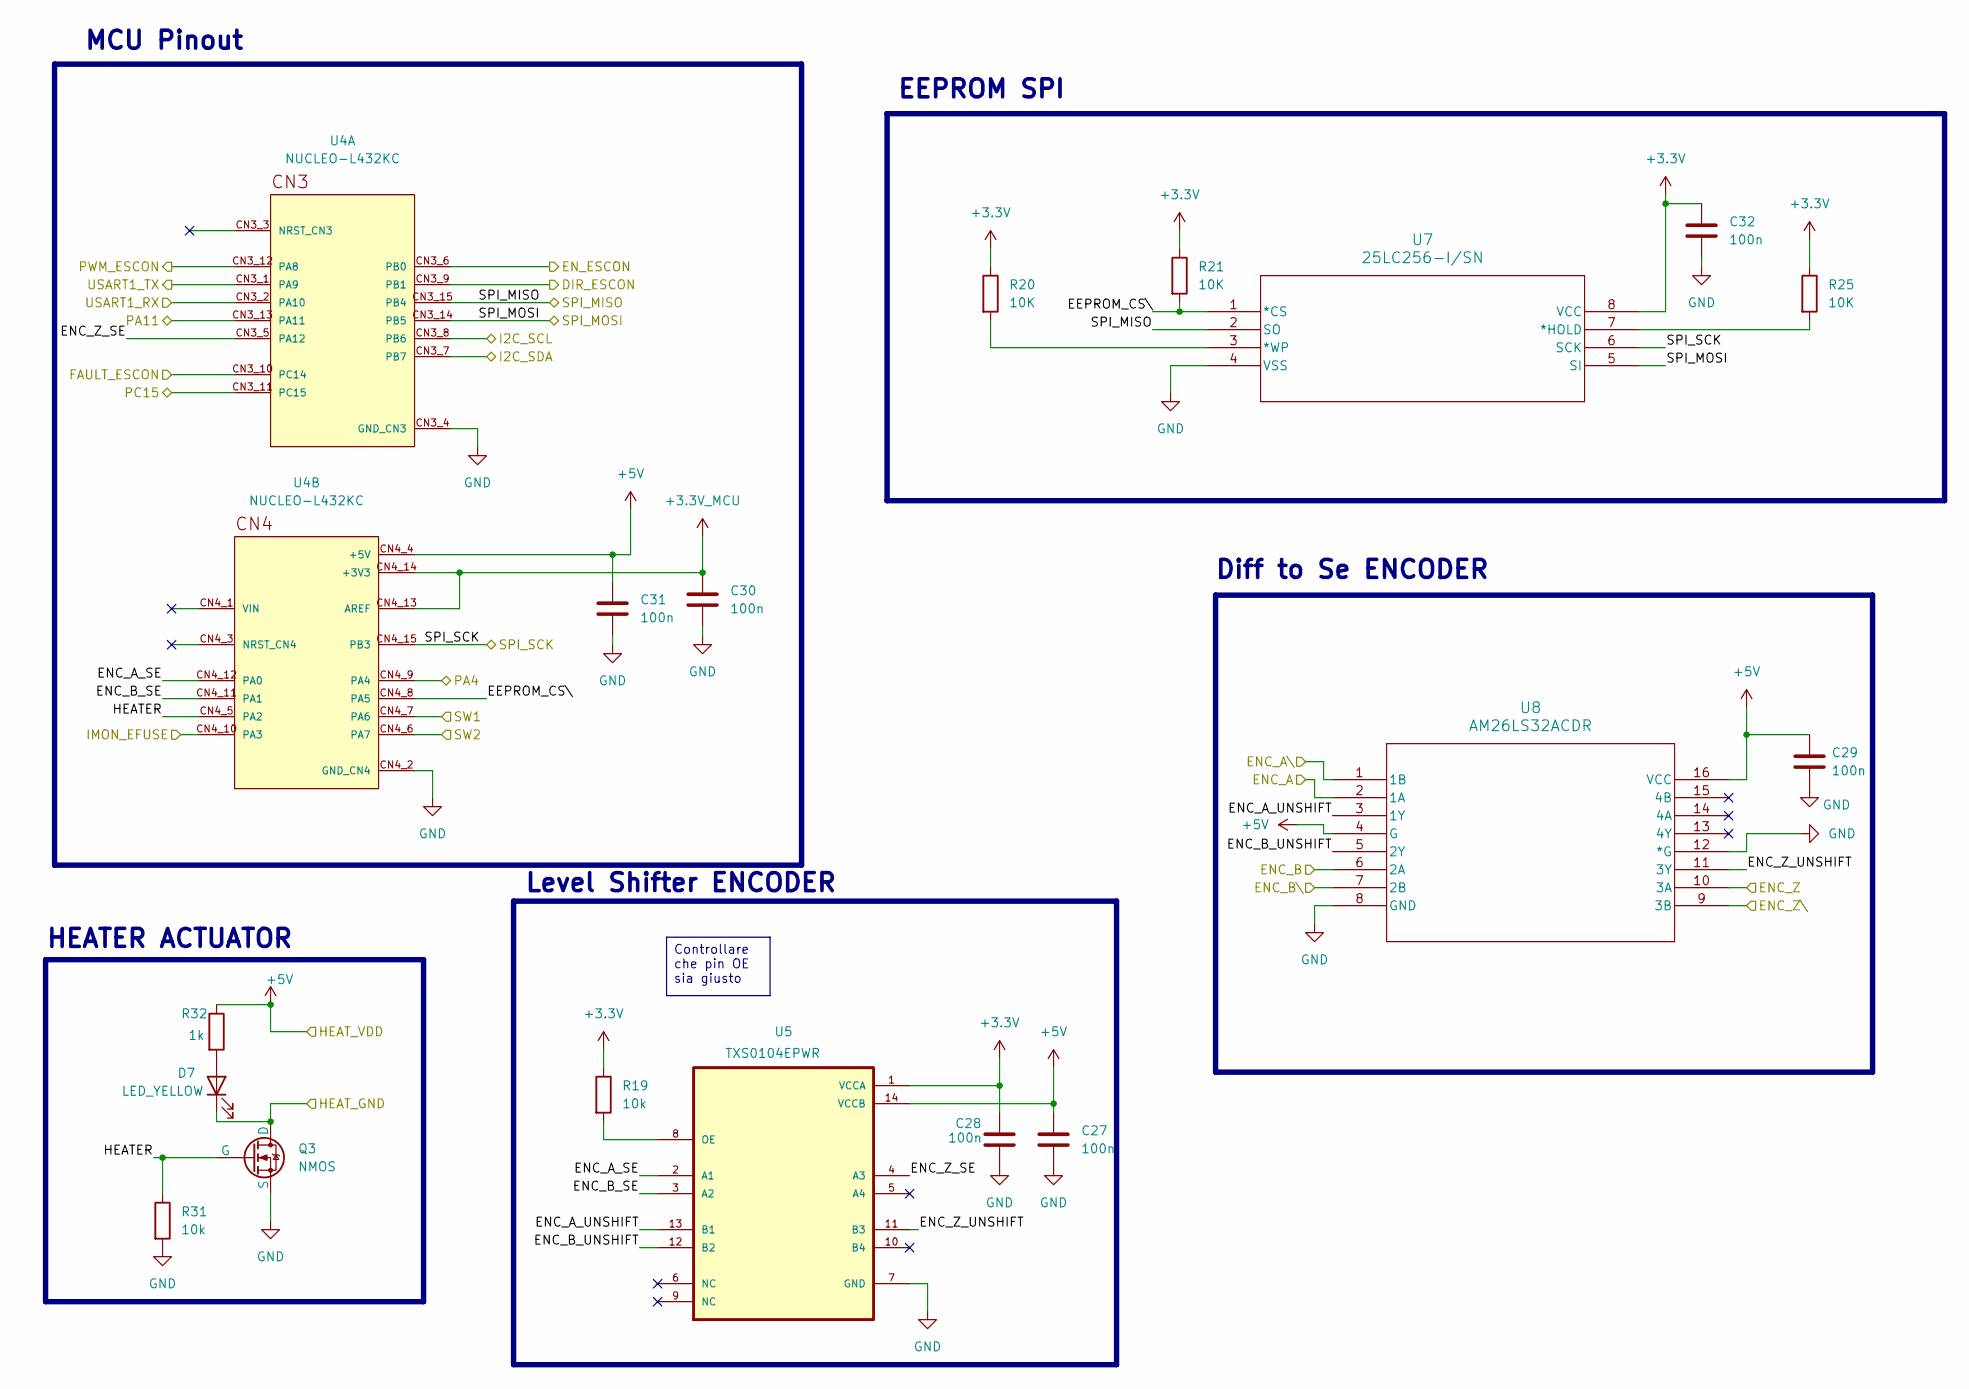
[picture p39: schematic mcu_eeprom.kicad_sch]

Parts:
C27, C28, C29, C30, C31, C32: 100n; C_1206_3216Metric_Pad1.33x1.80mm_HandSolder
D7: LED_YELLOW; LED_1206_3216Metric_Pad1.42x1.75mm_HandSolder
Q3: NMOS; SOT-23-3_L2.9-W1.3-P1.90-LS2.4-BR
R19, R31: 10k; R_1206_3216Metric_Pad1.30x1.75mm_HandSolder
R20, R21, R25: 10K; R_1206_3216Metric_Pad1.30x1.75mm_HandSolder
R32: 1k; R_1206_3216Metric_Pad1.30x1.75mm_HandSolder
U4: NUCLEO-L432KC; MODULE_NUCLEO-L432KC; PARTREV N/A
U5: TXS0104EPWR; SOP65P640X120-14N
U7: 25LC256-I/SN; SOIC8-N_MC_MCH
U8: AM26LS32ACDR; D16

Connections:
+3.3V: C28.1, C32.1, R19.1, R20.1, R21.1, R25.1, U5.1 (VCCA), U7.8 (VCC); also elsewhere on the board
+3.3V_MCU: C30.1, U4.CN4_13 (AREF), U4.CN4_14 (+3V3)
+5V: C27.1, C29.1, C31.1, R32.1, U4.CN4_4 (+5V), U5.14 (VCCB), U8.4 (G), U8.16 (VCC); also elsewhere on the board
/CONNECTORS/ENC_A: U8.2 (1A); also elsewhere on the board
/CONNECTORS/ENC_A\: U8.1 (1B); also elsewhere on the board
/CONNECTORS/ENC_B: U8.6 (2A); also elsewhere on the board
/CONNECTORS/ENC_B\: U8.7 (2B); also elsewhere on the board
/CONNECTORS/ENC_Z: U8.10 (3A); also elsewhere on the board
/CONNECTORS/ENC_Z\: U8.9 (3B); also elsewhere on the board
/CONNECTORS/ESCON_D_IN_1: U4.CN3_12 (PA8); also elsewhere on the board
/CONNECTORS/ESCON_D_IN_2: U4.CN3_6 (PB0); also elsewhere on the board
/CONNECTORS/ESCON_D_IO_3: U4.CN3_9 (PB1); also elsewhere on the board
/CONNECTORS/ESCON_D_IO_4: U4.CN3_10 (PC14); also elsewhere on the board
/CONNECTORS/HC_RX: U4.CN3_1 (PA9); also elsewhere on the board
/CONNECTORS/HC_TX: U4.CN3_2 (PA10); also elsewhere on the board
/CONNECTORS/HEAT_GND: D7.1 (K), Q3.1 (D); also elsewhere on the board
/CONNECTORS/PA3: U4.CN4_9 (PA4); also elsewhere on the board
/CONNECTORS/PA11: U4.CN3_13 (PA11); also elsewhere on the board
/CONNECTORS/PC15: U4.CN3_11 (PC15); also elsewhere on the board
/CONNECTORS/SCL: U4.CN3_8 (PB6); also elsewhere on the board
/CONNECTORS/SDA: U4.CN3_7 (PB7); also elsewhere on the board
/CONNECTORS/SW_1: U4.CN4_7 (PA6); also elsewhere on the board
/CONNECTORS/SW_2: U4.CN4_6 (PA7); also elsewhere on the board
/MCU+EEPROM/EEPROM_CS\: R21.2, U4.CN4_8 (PA5), U7.1 (*CS)
/MCU+EEPROM/ENC_A_SE: U4.CN4_12 (PA0), U5.2 (A1)
/MCU+EEPROM/ENC_A_UNSHIFT: U5.13 (B1), U8.3 (1Y)
/MCU+EEPROM/ENC_B_SE: U4.CN4_11 (PA1), U5.3 (A2)
/MCU+EEPROM/ENC_B_UNSHIFT: U5.12 (B2), U8.5 (2Y)
/MCU+EEPROM/ENC_Z_SE: U4.CN3_5 (PA12), U5.4 (A3)
/MCU+EEPROM/ENC_Z_UNSHIFT: U5.11 (B3), U8.11 (3Y)
/MCU+EEPROM/HEATER: Q3.2 (G), R31.1, U4.CN4_5 (PA2)
/MCU+EEPROM/IMON_EFUSE: U4.CN4_10 (PA3); also elsewhere on the board
/MCU+EEPROM/SPI_MISO: U4.CN3_15 (PB4), U7.2 (SO); also elsewhere on the board
/MCU+EEPROM/SPI_MOSI: U4.CN3_14 (PB5), U7.5 (SI); also elsewhere on the board
/MCU+EEPROM/SPI_SCK: U4.CN4_15 (PB3), U7.6 (SCK); also elsewhere on the board
GND: C27.2, C28.2, C29.2, C30.2, C31.2, C32.2, Q3.3 (S), R31.2, U4.CN3_4 (GND_CN3), U4.CN4_2 (GND_CN4), U5.7 (GND), U7.4 (VSS), U8.8 (GND), U8.12 (*G); also elsewhere on the board
unnamed: D7.2 (A), R32.2
unnamed: R19.2, U5.8 (OE)
unnamed: R25.2, U7.7 (*HOLD)
unnamed: R20.2, U7.3 (*WP)

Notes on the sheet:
EEPROM SPI
Level Shifter ENCODER
Diff to Se ENCODER
MCU Pinout
HEATER ACTUATOR
Controllare che pin OE sia giusto

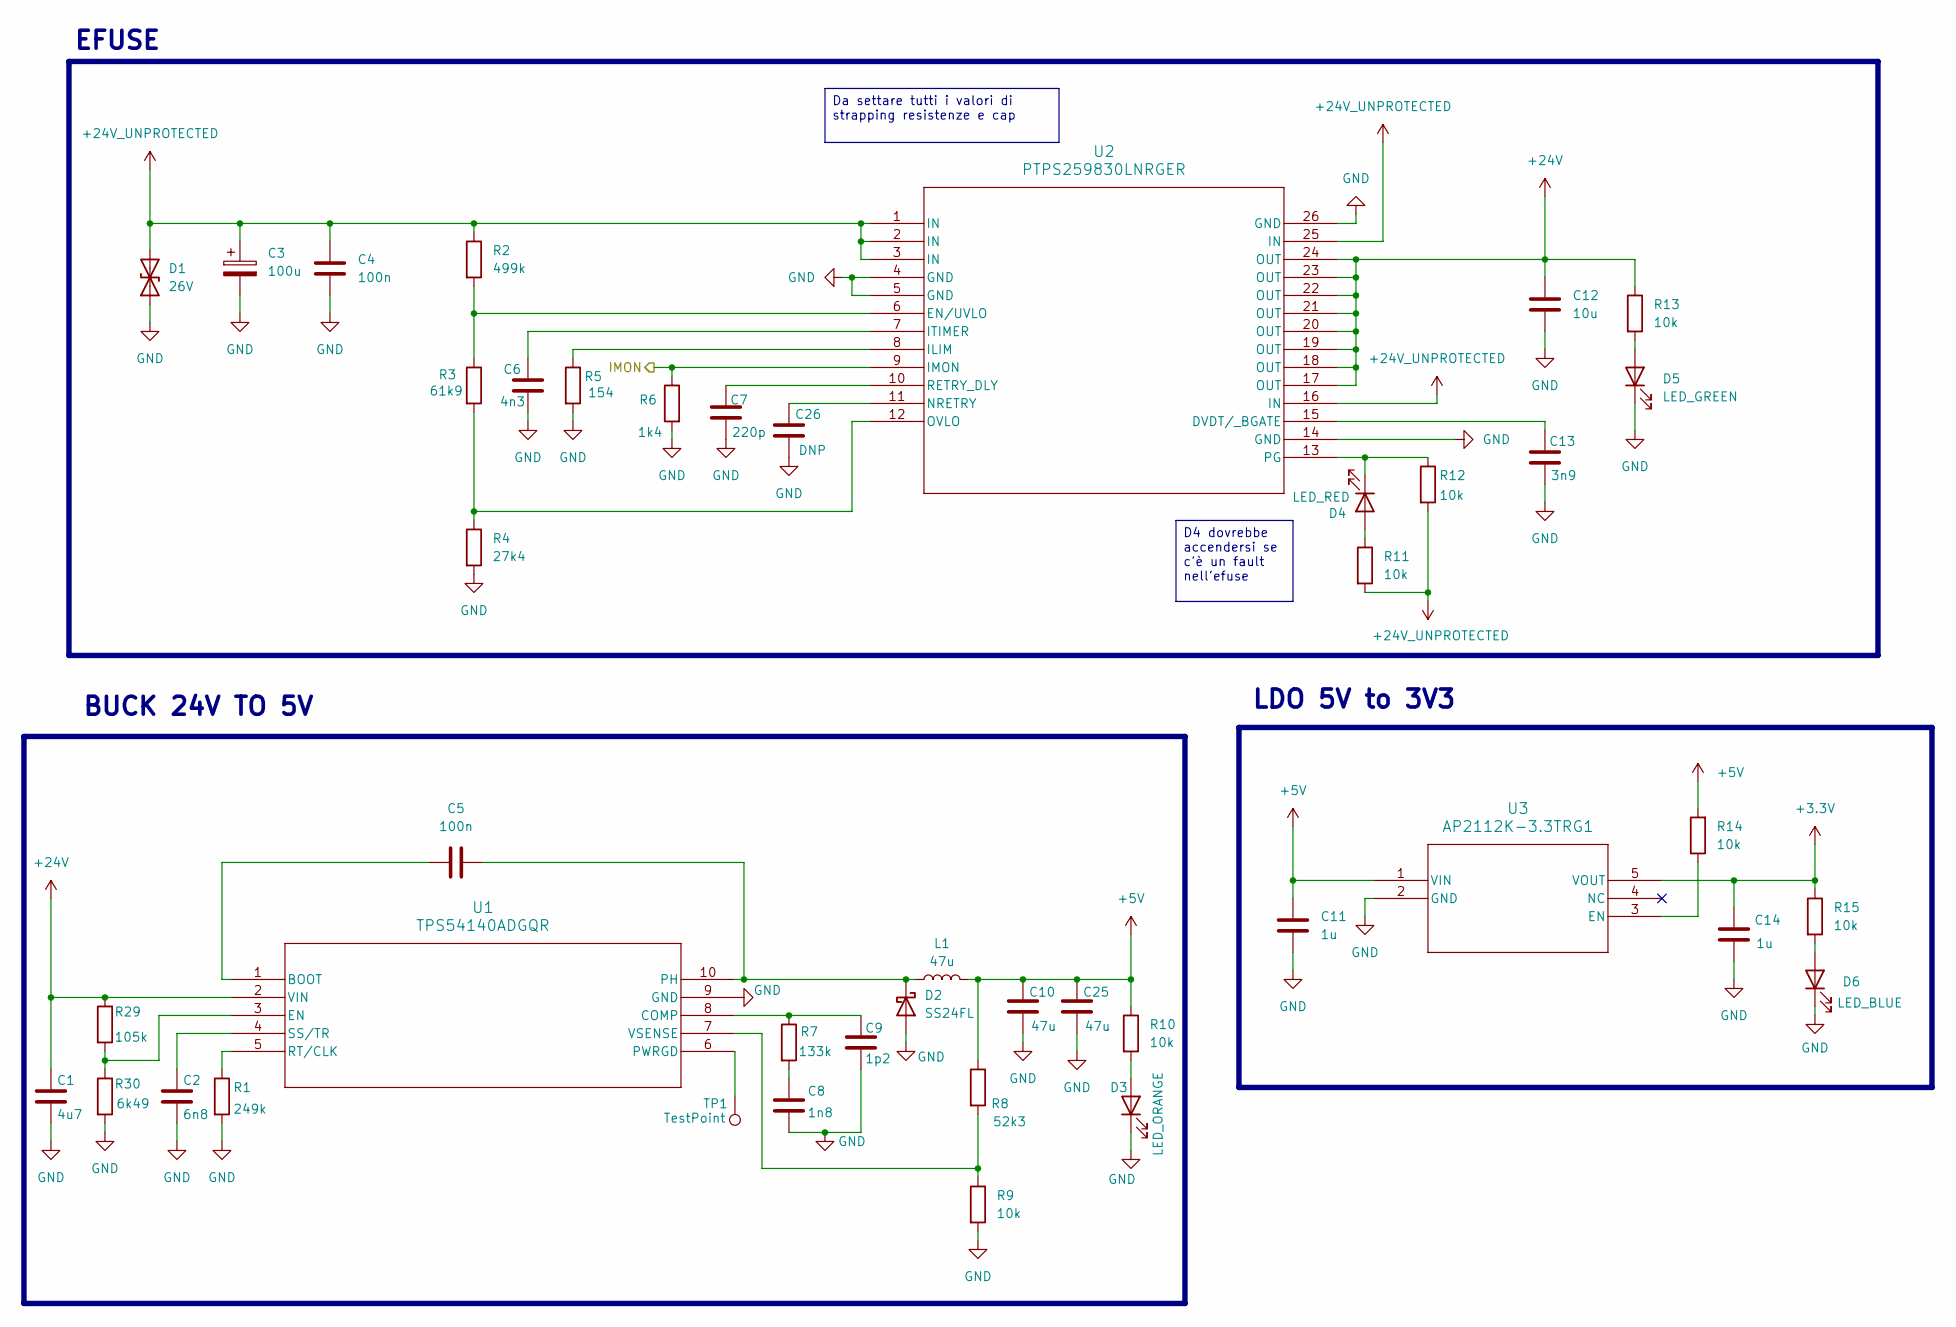
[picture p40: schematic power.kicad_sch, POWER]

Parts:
C1: 4u7; C_1206_3216Metric_Pad1.33x1.80mm_HandSolder
C2: 6n8; C_1206_3216Metric_Pad1.33x1.80mm_HandSolder
C3: 100u; C_Elec_10x10.2
C4, C5: 100n; C_1206_3216Metric_Pad1.33x1.80mm_HandSolder
C6: 4n3; C_1206_3216Metric_Pad1.33x1.80mm_HandSolder
C7: 220p; C_1206_3216Metric_Pad1.33x1.80mm_HandSolder
C8: 1n8; C_1206_3216Metric_Pad1.33x1.80mm_HandSolder
C9: 1p2; C_1206_3216Metric_Pad1.33x1.80mm_HandSolder
C10, C25: 47u; C_1206_3216Metric_Pad1.33x1.80mm_HandSolder
C11, C14: 1u; C_1206_3216Metric_Pad1.33x1.80mm_HandSolder
C12: 10u; C_1206_3216Metric_Pad1.33x1.80mm_HandSolder
C13: 3n9; C_1206_3216Metric_Pad1.33x1.80mm_HandSolder
C26: DNP; C_1206_3216Metric_Pad1.33x1.80mm_HandSolder
D1: 26V; SMB_L4.3-W3.6-LS5.4-BI
D2: SS24FL; SMA_L4.4-W2.8-LS5.4-RD
D3: LED_ORANGE; LED_1206_3216Metric_Pad1.42x1.75mm_HandSolder
D4: LED_RED; LED_1206_3216Metric_Pad1.42x1.75mm_HandSolder
D5: LED_GREEN; LED_1206_3216Metric_Pad1.42x1.75mm_HandSolder
D6: LED_BLUE; LED_1206_3216Metric_Pad1.42x1.75mm_HandSolder
L1: 47u; IND-SMD_L13.5-W12.6_125CDMCC-DS
R1: 249k; R_1206_3216Metric_Pad1.30x1.75mm_HandSolder
R2: 499k; R_1206_3216Metric_Pad1.30x1.75mm_HandSolder
R3: 61k9; R_1206_3216Metric_Pad1.30x1.75mm_HandSolder
R4: 27k4; R_1206_3216Metric_Pad1.30x1.75mm_HandSolder
R5: 154; R_1206_3216Metric_Pad1.30x1.75mm_HandSolder
R6: 1k4; R_1206_3216Metric_Pad1.30x1.75mm_HandSolder
R7: 133k; R_1206_3216Metric_Pad1.30x1.75mm_HandSolder
R8: 52k3; R_1206_3216Metric_Pad1.30x1.75mm_HandSolder
R9, R10, R11, R12, R13, R14, R15: 10k; R_1206_3216Metric_Pad1.30x1.75mm_HandSolder
R29: 105k; R_1206_3216Metric_Pad1.30x1.75mm_HandSolder
R30: 6k49; R_1206_3216Metric_Pad1.30x1.75mm_HandSolder
TP1: TestPoint; TestPoint_Pad_D2.5mm
U1: TPS54140ADGQR; DGQ10_1P88X1P57_TEX
U2: PTPS259830LNRGER; VQFN24_RGE_TEX
U3: AP2112K-3.3TRG1; SOT_RG1_DIO

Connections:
+3.3V: C14.1, R15.1, U3.5 (VOUT); also elsewhere on the board
+5V: C10.1, C11.1, C25.1, L1.2, R8.1, R10.1, R14.2, U3.1 (VIN); also elsewhere on the board
+24V: C1.1, C12.1, R13.1, R29.1, U1.2 (VIN), U2.17 (OUT), U2.18 (OUT), U2.19 (OUT), U2.20 (OUT), U2.21 (OUT), U2.22 (OUT), U2.23 (OUT), U2.24 (OUT); also elsewhere on the board
+24V_UNPROTECTED: C3.1, C4.1, D1.2 (A2), R2.1, R11.2, R12.2, U2.1 (IN), U2.2 (IN), U2.3 (IN), U2.16 (IN), U2.25 (IN); also elsewhere on the board
/MCU+EEPROM/IMON_EFUSE: R6.1, U2.9 (IMON); also elsewhere on the board
GND: C1.2, C2.2, C3.2, C4.2, C6.2, C7.2, C8.2, C9.2, C10.2, C11.2, C12.2, C13.2, C14.2, C25.2, C26.2, D1.1 (A1), D2.2 (A), D3.1 (K), D5.1 (K), D6.1 (K), R1.2, R4.2, R5.2, R6.2, R9.2, R30.2, U1.9 (GND), U2.4 (GND), U2.5 (GND), U2.14 (GND), U2.26 (GND), U3.2 (GND); also elsewhere on the board
unnamed: C8.1, R7.2
unnamed: C5.2, D2.1 (K), L1.1, U1.10 (PH)
unnamed: D3.2 (A), R10.2
unnamed: D4.2 (A), R11.1
unnamed: D4.1 (K), R12.1, U2.13 (PG)
unnamed: D5.2 (A), R13.2
unnamed: D6.2 (A), R15.2
unnamed: C5.1, U1.1 (BOOT)
unnamed: C9.1, R7.1, U1.8 (COMP)
unnamed: R29.2, R30.1, U1.3 (EN)
unnamed: TP1.1 (1_1), U1.6 (PWRGD)
unnamed: R1.1, U1.5 (RT/CLK)
unnamed: C2.1, U1.4 (SS/TR)
unnamed: R8.2, R9.1, U1.7 (VSENSE)
unnamed: C13.1, U2.15 (DVDT/_BGATE)
unnamed: R2.2, R3.1, U2.6 (EN/UVLO)
unnamed: R5.1, U2.8 (ILIM)
unnamed: C6.1, U2.7 (ITIMER)
unnamed: C26.1, U2.11 (NRETRY)
unnamed: R3.2, R4.1, U2.12 (OVLO)
unnamed: C7.1, U2.10 (RETRY_DLY)
unnamed: R14.1, U3.3 (EN)

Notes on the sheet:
BUCK 24V TO 5V
LDO 5V to 3V3
EFUSE
Da settare tutti i valori di strapping resistenze e cap
D4 dovrebbe accendersi se c'è un fault nell'efuse

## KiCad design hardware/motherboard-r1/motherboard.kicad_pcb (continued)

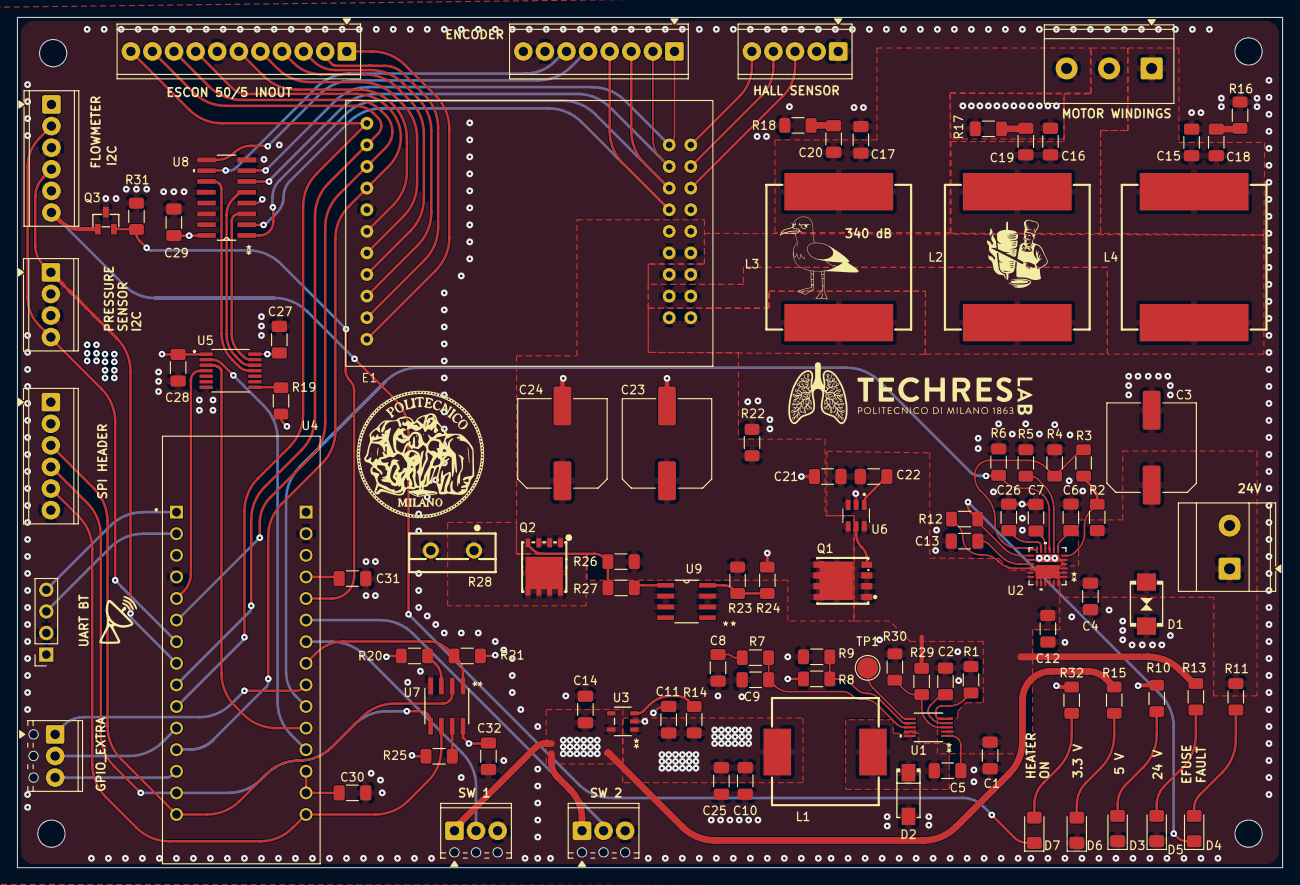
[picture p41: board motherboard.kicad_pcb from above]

Board: 4 copper layers, 148.8 x 100.0 mm, 105 parts (0 on the bottom side), 89 nets.

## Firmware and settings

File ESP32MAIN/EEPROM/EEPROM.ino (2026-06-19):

#include <Wire.h>
#include <SPI.h>
#include <BLEDevice.h>
#include <BLEServer.h>
#include <BLEUtils.h>
#include <BLE2902.h>
#include <math.h>

// ── UART ─────────────────────────────────────────────────────────
#define UART_TX     17
#define UART_RX     16

// ── ENCODER ──────────────────────────────────────────────────────
#define ENC_A       34
#define ENC_B       35
#define ENC_Z        4

// ── PWM + 2 GPIO OUT ─────────────────────────────────────────────
#define PWM_OUT     15
#define GPIO_OUT_1  25       // EN
#define GPIO_OUT_2  26       // DIR

// ── 2 GPIO IN con INTERRUPT ──────────────────────────────────────
#define GPIO_IRQ_1  32
#define GPIO_IRQ_2  33

// ── 2 GPIO OUT aggiuntivi ────────────────────────────────────────
#define GPIO_OUT_3  27
#define GPIO_OUT_4  14

// ── 2 GPIO IN aggiuntivi ─────────────────────────────────────────
#define GPIO_IN_1   39
#define GPIO_IN_2   13

// ── I2C ──────────────────────────────────────────────────────────
#define SDP_ADDR    0x25
#define SFM_ADDR    0x40
#define I2C_SDA     21
#define I2C_SCL     22

// ── SPI / EEPROM ─────────────────────────────────────────────────
#define PIN_CS      5
#define EEPROM_WREN   0x06
#define EEPROM_RDSR   0x05
#define EEPROM_WRITE  0x02
#define EEPROM_READ   0x03
#define EEPROM_PAGE_SIZE   64
#define EEPROM_TOTAL_SIZE  32768

SPIClass vspi(VSPI);
SPISettings eepromSettings(1000000, MSBFIRST, SPI_MODE0);

static inline void CS_Low()  { digitalWrite(PIN_CS, LOW);  }
static inline void CS_High() { digitalWrite(PIN_CS, HIGH); }

// ── Costanti di conversione ───────────────────────────────────────
const float SDP_SCALE_FACTOR = 60.0f;
const float SFM_SCALE_FACTOR = 120.0f;
const int16_t SFM_OFFSET     = 32768;

// ── Tipo di sensore ───────────────────────────────────────────────
enum TipoSensore { NESSUNO, SDP810, SFM3300 };
TipoSensore sensoreAttivo = NESSUNO;

// ── Stati del Sistema ─────────────────────────────────────────────
enum Modalita {
    MODE_DEBUG = 1000,
    MODE_LINEAR = 0,
    MODE_SINUSOIDAL = 1,
    MODE_CALIBRATION = 2,
    MODE_PUSH = 3,
    MODE_HOME = 4,
    MODE_IDLE = 5
};
volatile Modalita stato = MODE_IDLE; // Stato iniziale di sicurezza

// ── Variabili PID e Target ────────────────────────────────────────
float Kp = 1.0f;
float Ki = 0.1f;
float Kd = 0.05f;

float integral = 0.0f;
float prev_error = 0.0f;
unsigned long prev_time_pid = 0;

float target_flow = 0.0f;     // Per Mode 0 (L/s)
float sine_amplitude = 0.0f;  // Per Mode 1 (L/s)
float sine_frequency = 0.0f;  // Per Mode 1 (Hz)
unsigned long start_time_mode1 = 0;
int divisore;
int pwmValue;
    float current_flow = 0.0f;

// ── BLE HM10 Config ───────────────────────────────────────────────
#define HM10_SERVICE_UUID      "0000FFE0-0000-1000-8000-00805F9B34FB"
#define HM10_UART_CHAR_UUID    "0000FFE1-0000-1000-8000-00805F9B34FB"

BLEServer *pServer = NULL;
BLECharacteristic * pTxCharacteristic = NULL;
bool deviceConnected = false;
String msg_BLE = ""; // Buffer per i messaggi BLE in arrivo

// ── Variabili "dummy" per il parser ───────────────────────────────
int parametri_int[5] = {0};
float parametri_float[5] = {0.0};
char msg[128] = "";
bool read_SDP810 = false;
void SFM3300_Start() {} 
void SFM3300_Stop() {}  
void I2C_Scan() {}      
float resistenza = 1.0f; // Inizializzata qui, NON dentro il loop!

// ── Timer hardware 200 Hz ─────────────────────────────────────────
hw_timer_t* timer200Hz = nullptr;
volatile bool campiona  = false;

// ── Timer stampa EEPROM ───────────────────────────────────────────
unsigned long ultimo_tempo_stampa_ms = 0;
const unsigned long INTERVALLO_STAMPA_MS = 1000;
String stringaRicevuta = "";

// ── VARIABILI ENCODER ─────────────────────────────────────────────
volatile long encoder_pos = 0; // Posizione attuale dell'encoder

// ── Dichiarazioni ─────────────────────────────────────────────────
TipoSensore rilevaSensore();
float leggi_SDP810();
float leggi_SFM3300();
void EEPROM_SPI_Init();
void write_EEPROM(const char* str);
char* read_EEPROM();
static void EEPROM_WaitReady();
static void EEPROM_WriteEnable();
void parser();
void setMotor(float speed, bool dir, bool enable);
void send_BLE(const String& messaggio);

/* ══════════════════════════════════════════════════════════════
 * ISR (Interrupt Service Routines)
 * ══════════════════════════════════════════════════════════════ */
void IRAM_ATTR onTimer200Hz() {
    campiona = true;
}

// ISR per lo stop immediato di emergenza dai pin di ingresso hardware
void IRAM_ATTR onEmergencyStop() {
    stato = MODE_IDLE;
    digitalWrite(GPIO_OUT_1, LOW); // Disabilita motore
    analogWrite(PWM_OUT, 0);       // Spegne il segnale PWM
}

// ISR per leggere l'encoder in quadratura
void IRAM_ATTR onEncoderISR() {
    // Tabella di lookup per decodificare la quadratura in modo ultra-veloce
    static int8_t lookup_table[] = {0,-1,1,0,1,0,0,-1,-1,0,0,1,0,1,-1,0};
    static uint8_t enc_val = 0;
    
    enc_val = enc_val << 2;
    enc_val = enc_val | ((digitalRead(ENC_A) << 1) | digitalRead(ENC_B));
    
    encoder_pos += lookup_table[enc_val & 0b1111];
}

/* ══════════════════════════════════════════════════════════════
 * BLE CALLBACKS
 * ══════════════════════════════════════════════════════════════ */
class MyServerCallbacks: public BLEServerCallbacks {
    void onConnect(BLEServer* pServer) {
      deviceConnected = true;
    };
    void onDisconnect(BLEServer* pServer) {
      deviceConnected = false;
      pServer->startAdvertising(); // Riavvia l'advertising per nuove connessioni
    }
};

class MyCallbacks: public BLECharacteristicCallbacks {
    void onWrite(BLECharacteristic *pCharacteristic) {
      String rxValue = pCharacteristic->getValue(); 
      
      if (rxValue.length() > 0) {
        Serial.print(rxValue); 
        
        for (int i = 0; i < rxValue.length(); i++) {
          char c = rxValue[i];
          if (c == '\n' || c == '\r') {
            if (msg_BLE.length() > 0) {
              parser();
              msg_BLE = ""; 
            }
          } else {
            msg_BLE += c;
          }
        }
      }
    }
};

/* ══════════════════════════════════════════════════════════════
 * SETUP
 * ══════════════════════════════════════════════════════════════ */
void setup()
{
    Serial.begin(115200);
    while (!Serial) { delay(10); }
    delay(2000);
    divisore = 0;
    pwmValue = 0;
    current_flow = 0.0f;

    // --- Inizializzazione Pin Motore ---
    pinMode(PWM_OUT, OUTPUT);
    pinMode(GPIO_OUT_1, OUTPUT); // EN
    pinMode(GPIO_OUT_2, OUTPUT); // DIR
    
    // --- Inizializzazione Pin Emergenza ---
    pinMode(GPIO_IRQ_1, INPUT_PULLUP);
    pinMode(GPIO_IRQ_2, INPUT_PULLUP);
    attachInterrupt(digitalPinToInterrupt(GPIO_IRQ_1), onEmergencyStop, FALLING);
    attachInterrupt(digitalPinToInterrupt(GPIO_IRQ_2), onEmergencyStop, FALLING);

    // --- Inizializzazione Pin Encoder ---
    pinMode(ENC_A, INPUT); 
    pinMode(ENC_B, INPUT);
    pinMode(ENC_Z, INPUT_PULLDOWN); // Pin Z (Index). Se il tuo encoder è attivo basso, usa INPUT_PULLUP
    
    attachInterrupt(digitalPinToInterrupt(ENC_A), onEncoderISR, CHANGE);
    attachInterrupt(digitalPinToInterrupt(ENC_B), onEncoderISR, CHANGE);

    setMotor(0, false, false);

    // --- Inizializzazione BLE ---
    BLEDevice::init("Polmone"); 
    pServer = BLEDevice::createServer();
    pServer->setCallbacks(new MyServerCallbacks());

    BLEService *pService = pServer->createService(HM10_SERVICE_UUID);
    pTxCharacteristic = pService->createCharacteristic(
                      HM10_UART_CHAR_UUID,
                      BLECharacteristic::PROPERTY_NOTIFY |
                      BLECharacteristic::PROPERTY_WRITE  |
                      BLECharacteristic::PROPERTY_WRITE_NR
                    );

    pTxCharacteristic->setCallbacks(new MyCallbacks());
    pTxCharacteristic->addDescriptor(new BLE2902());
    pService->start();
    pServer->getAdvertising()->start();
    Serial.println("BLE Inizializzato [Polmone]. In attesa di accoppiamento...");

    // --- Inizializzazione EEPROM ---
    EEPROM_SPI_Init();
    delay(100);

    Serial.print("Contenuto EEPROM: ");
    Serial.println(read_EEPROM());

    // --- Inizializzazione I2C e Sensori ---
    Wire.begin(I2C_SDA, I2C_SCL);
    Wire.setClock(400000);

    Serial.println("\n--- Scansione Sensore in Corso... ---");
    sensoreAttivo = rilevaSensore();

    if (sensoreAttivo == SDP810) {
        Serial.println("Rilevato: SDP810. Avvio modalità continua...");
        Wire.beginTransmission(SDP_ADDR);
        Wire.write(0x36); Wire.write(0x15);
        Wire.endTransmission();
    }
    else if (sensoreAttivo == SFM3300) {
        Serial.println("Rilevato: SFM3300.");
    }
    else {
        Serial.println("ERRORE: Nessun sensore trovato!");
    }

    // --- Timer a 200Hz ---
    timer200Hz = timerBegin(1000000); 
    timerAttachInterrupt(timer200Hz, &onTimer200Hz);
    timerAlarm(timer200Hz, 5000, true, 0); // 5000 µs = 200 Hz

    ultimo_tempo_stampa_ms = millis();
    prev_time_pid = millis();
}

/* ══════════════════════════════════════════════════════════════
 * LOOP
 * ══════════════════════════════════════════════════════════════ */
void loop()
{
    unsigned long tempo_attuale_ms = millis();
    static int tempo = 0;

    /* ── 1. LETTURA SERIALE UART E PONTE ──────────────────────── */
    while (Serial.available() > 0) {
        char c = Serial.read();
        if (c == '\n' || c == '\r') {
            if (stringaRicevuta.length() > 0) {
                send_BLE(stringaRicevuta);
                stringaRicevuta = "";
            }
        } else {
            if (stringaRicevuta.length() < (EEPROM_TOTAL_SIZE - 1))
                stringaRicevuta += c;
        }
    }

    /* ── 2. STAMPA CONTATORE OGNI 1 SECONDO ──────────────────── */
    if (tempo_attuale_ms - ultimo_tempo_stampa_ms >= INTERVALLO_STAMPA_MS) {
        Serial.print("Tempo: ");
        Serial.print(tempo);
        Serial.print(" | Posizione Encoder: ");
        Serial.println(encoder_pos);
        
        send_BLE(String("Tempo: ") + tempo + String(" Stato: ") + (int)stato + String(" Enc: ") + encoder_pos);
        tempo++;
        ultimo_tempo_stampa_ms = tempo_attuale_ms;
        if(tempo%10==0 || true){
                
        }
        
    }

    /* ── 3. CAMPIONAMENTO E GESTIONE PID (200 Hz) ────────────── */
    if (campiona) {
        campiona = false;
        
        // --- LETTURA E AZZERAMENTO ENCODER ---
        // Se il pin Z va alto, azzera la posizione (Home automatico ad ogni giro)
        if (digitalRead(ENC_Z) == HIGH) {
            encoder_pos = 0;
        }
        
        // Salvataggio sicuro della posizione in locale
        long posizione_corrente = encoder_pos;

        // --- ACQUISIZIONE SENSORE E PID ---
        float valoreletto = NAN;

        if (sensoreAttivo == SDP810) {
            valoreletto = leggi_SDP810();
            if (!isnan(valoreletto)) {
                current_flow = valoreletto * resistenza; 
            }
        }
        else if (sensoreAttivo == SFM3300) {
            valoreletto = leggi_SFM3300();
            if (!isnan(valoreletto)) {
               current_flow = valoreletto; 
            }
        }

        if (!isnan(valoreletto) && (stato == MODE_LINEAR || stato == MODE_SINUSOIDAL)) {
            unsigned long current_time = millis();
            float dt = (current_time - prev_time_pid) / 1000.0f;
            
            if (dt <= 0.0f) dt = 0.005f; 
            prev_time_pid = current_time;

            float setpoint = 0.0f;

            if (stato == MODE_LINEAR) {
                setpoint = target_flow;
            } 
            else if (stato == MODE_SINUSOIDAL) {
                float t = (current_time - start_time_mode1) / 1000.0f;
                setpoint = sine_amplitude * sin(2.0 * M_PI * sine_frequency * t);
            }

            float error = setpoint - current_flow;
            integral += error * dt;
            
            if (integral > 200.0f) integral = 200.0f;
            if (integral < -200.0f) integral = -200.0f;

            float derivative = (error - prev_error) / dt;
            float output = (Kp * error) + (Ki * integral) + (Kd * derivative);
            prev_error = error;

            bool forward = (output >= 0);
            float motor_speed = fabs(output); 
            
            if (motor_speed > 255.0f) motor_speed = 255.0f;

            setMotor(motor_speed, forward, true);
        }

        send_BLE(String("SNSR ")+current_flow+" "+encoder_pos+ " "+ pwmValue);
        //FINE IF SCANNING
    }
}
// FINE CAMPIONAMENTO

/* ══════════════════════════════════════════════════════════════
 * CONTROLLO MOTORE
 * ══════════════════════════════════════════════════════════════ */
void setMotor(float speed, bool dir, bool enable) {
    if (stato == MODE_IDLE) {
        enable = false;
        speed = 0.0f;
    }

    digitalWrite(GPIO_OUT_1, enable ? HIGH : LOW);
    digitalWrite(GPIO_OUT_2, dir ? HIGH : LOW);

    if (!enable) {
        analogWrite(PWM_OUT, 0);
        return;
    }

    float normalized_speed = 0.0f;
    if (speed <= 1.0f && speed >= 0.0f) {
        normalized_speed = speed; 
    } else {
        normalized_speed = speed / 255.0f; 
    }

    if (normalized_speed > 1.0f) normalized_speed = 1.0f;
    if (normalized_speed < 0.0f) normalized_speed = 0.0f;

    int minPWM = 26;  // ~10% di 255
    int maxPWM = 230; // ~90% di 255

    pwmValue = minPWM + (int)(normalized_speed * (maxPWM - minPWM));

    analogWrite(PWM_OUT, pwmValue);
}

/* ══════════════════════════════════════════════════════════════
 * FUNZIONE INVIO MESSAGGI BLE
 * ══════════════════════════════════════════════════════════════ */
void send_BLE(const String& messaggio) {
    if (deviceConnected && pTxCharacteristic != NULL) {
        String payload = messaggio + "\r\n";
        pTxCharacteristic->setValue(payload.c_str());
        pTxCharacteristic->notify();
    }
}

/* ══════════════════════════════════════════════════════════════
 * PARSER COMANDI RICEVUTI
 * ══════════════════════════════════════════════════════════════ */
void parser() {
    int statoLetto = -1;
    float r_parz = 0.0f;
    const char* parsed = msg_BLE.c_str();

    if (sscanf(parsed,"STOP")==1){
        stato = MODE_IDLE;
        Serial.printf("STOP eseguito\n");
        send_BLE(String("STOP eseguito"));
    }
    if (sscanf(parsed, "R : %f", &r_parz) == 1){
        resistenza = r_parz;
        Serial.printf("Nuova resistenza impostata: %.3f\n", resistenza);
        return; 
    }

    if (sscanf(parsed, "Mode %d", &statoLetto) == 1) {
        stato = (Modalita)statoLetto;

        switch (statoLetto) {
        case 0:
            if (sscanf(parsed, "Mode 0 %f", &target_flow) == 1) {
                integral = 0.0f;
                prev_error = 0.0f;
                prev_time_pid = millis();
                Serial.printf("Avviato PID Lineare. Target: %.2f L/s\n", target_flow);
            }
            break;

        case 1:
            if (sscanf(parsed, "Mode 1 %f %f", &sine_amplitude, &sine_frequency) == 2) {
                integral = 0.0f;
                prev_error = 0.0f;
                start_time_mode1 = millis();
                prev_time_pid = start_time_mode1;
                Serial.printf("Avviato PID Sinusoide. Amp: %.2f, Freq: %.2f Hz\n", sine_amplitude, sine_frequency);
            }
            break;

        case 2: 
            if (parametri_int[0] == 1) {
                setMotor(1.0f, true, true);
            } else {
                setMotor(parametri_float[0] / 1000.0f, false, true);
            }
            break;

        case 5:        
            setMotor(0, false, false);
            break;

        case 6: // RESET MANUALE ENCODER (da BLE inviare "Mode 6")
            encoder_pos = 0;
            Serial.println("Encoder azzerato via BLE");
            send_BLE("Encoder azzerato");
            break;
            
        case 512: // EEPROM WRITE
            {
                char auxStr[64] = {0}; 
                if (sscanf(parsed, "Mode 512 %63s", auxStr) == 1) {
                    write_EEPROM(auxStr);
                }
            }
            break;
            
        case 513: // EEPROM READ
            { char* letto = read_EEPROM(); }
            break;
            
        case 514: // SDP_READLOOP
            SFM3300_Start();
            read_SDP810 = true;
            break;
            
        case 515: // SDP_WRITE_LOOP
            read_SDP810 = false;
            SFM3300_Stop();
            break;
            
        case 516:
            send_BLE(String("TROVATO: ") + rilevaSensore());
            break;
        case 517: //scrittura motore
            setMotor(60.0f, true, true);
            break;
        default:
            break;
        }
    }
}

/* ══════════════════════════════════════════════════════════════
 * FUNZIONI PERIFERICHE ORIGINALI (I2C ed EEPROM SPI)
 * ══════════════════════════════════════════════════════════════ */
TipoSensore rilevaSensore() {
    int trovati = 0;
    for (byte addr = 0x01; addr < 0x7F; addr++) {
        Wire.beginTransmission(addr);
        if (Wire.endTransmission() == 0) trovati++;
    }
    Wire.beginTransmission(SDP_ADDR);
    if (Wire.endTransmission() == 0) return SDP810;
    Wire.beginTransmission(SFM_ADDR);
    Wire.write(0x10); Wire.write(0x00);
    if (Wire.endTransmission() == 0) {
        delay(100);
        Wire.requestFrom(SFM_ADDR, 3);
        while (Wire.available()) Wire.read();
        return SFM3300;
    }
    return NESSUNO;
}

float leggi_SDP810() {
    Wire.requestFrom(SDP_ADDR, 3);
    if (Wire.available() >= 3) {
        int16_t raw = (Wire.read() << 8) | Wire.read();
        Wire.read(); 
        return (float)raw / SDP_SCALE_FACTOR;
    }
    return NAN;
}

float leggi_SFM3300() {
    Wire.requestFrom(SFM_ADDR, 3);
    if (Wire.available() >= 3) {
        uint16_t raw = (Wire.read() << 8) | Wire.read();
        Wire.read(); 
        return (float)((int32_t)raw - SFM_OFFSET) / SFM_SCALE_FACTOR;
    }
    return NAN;
}

void EEPROM_SPI_Init() {
    pinMode(PIN_CS, OUTPUT);
    CS_High();
    vspi.begin(18, 19, 23, PIN_CS);
}

static void EEPROM_WaitReady() {
    uint8_t status;
    do {
        vspi.beginTransaction(eepromSettings);
        CS_Low(); vspi.transfer(EEPROM_RDSR); status = vspi.transfer(0x00); CS_High();
        vspi.endTransaction();
        delayMicroseconds(100);
    } while (status & 0x01);
}

static void EEPROM_WriteEnable() {
    vspi.beginTransaction(eepromSettings);
    CS_Low(); vspi.transfer(EEPROM_WREN); CS_High();
    vspi.endTransaction();
}

void write_EEPROM(const char* str) {
    for (uint16_t addr = 0; addr < EEPROM_TOTAL_SIZE; addr += EEPROM_PAGE_SIZE) {
        EEPROM_WriteEnable();
        vspi.beginTransaction(eepromSettings);
        CS_Low(); vspi.transfer(EEPROM_WRITE);
        vspi.transfer((addr >> 8) & 0xFF); vspi.transfer(addr & 0xFF);
        for (int i = 0; i < EEPROM_PAGE_SIZE; i++) vspi.transfer(0xFF);
        CS_High();
        vspi.endTransaction();
        EEPROM_WaitReady();
    }
    uint16_t bytes_left = (uint16_t)strlen(str) + 1;
    uint16_t src_offset = 0;
    uint16_t addr = 0x0000;
    while (bytes_left > 0) {
        uint16_t chunk = (bytes_left < EEPROM_PAGE_SIZE) ? bytes_left : EEPROM_PAGE_SIZE;
        EEPROM_WriteEnable();
        vspi.beginTransaction(eepromSettings);
        CS_Low(); vspi.transfer(EEPROM_WRITE);
        vspi.transfer((addr >> 8) & 0xFF); vspi.transfer(addr & 0xFF);
        for (uint16_t i = 0; i < chunk; i++) vspi.transfer((uint8_t)str[src_offset + i]);
        CS_High();
        vspi.endTransaction();
        EEPROM_WaitReady();
        addr += chunk; src_offset += chunk; bytes_left -= chunk;
    }
}

char* read_EEPROM() {
    static char result[EEPROM_TOTAL_SIZE];
    vspi.beginTransaction(eepromSettings);
    CS_Low(); vspi.transfer(EEPROM_READ); vspi.transfer(0x00); vspi.transfer(0x00);
    for (uint16_t i = 0; i < EEPROM_TOTAL_SIZE; i++) {
        result[i] = (char)vspi.transfer(0x00);
        if (result[i] == '\0') break;
    }
    CS_High(); vspi.endTransaction();
    result[EEPROM_TOTAL_SIZE - 1] = '\0';
    return result;
}

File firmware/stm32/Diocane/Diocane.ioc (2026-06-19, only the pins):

Mcu.UserName=STM32L432KCUx
PA10.Signal=USART1_RX
PA2.Signal=USART2_TX
PA3.Signal=USART2_RX
PA5.GPIO_Label=EEPROM_CS
PA5.Signal=GPIO_Output
PA6.GPIO_Label=MicroSwitch1
PA6.Signal=GPIO_Input
PA7.GPIO_Label=MicroSwitch2
PA7.Signal=GPIO_Input
PA8.GPIO_Label=PWM_ESCON
PA8.Signal=S_TIM1_CH1
PA9.Signal=USART1_TX
PB0.GPIO_Label=ESCON_ENABLE
PB0.Signal=GPIO_Output
PB1.GPIO_Label=ESCON_DIRECTION
PB1.Signal=GPIO_Output
PB5.Signal=SPI1_MOSI
PB6.Signal=I2C1_SCL
PB7.Signal=I2C1_SDA

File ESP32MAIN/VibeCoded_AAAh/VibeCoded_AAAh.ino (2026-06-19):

#include <Wire.h>
#include <SPI.h>
#include <ESP32Encoder.h>
#include <NimBLEDevice.h>

// ── CONFIGURAZIONE PINOUT ────────────────────────────────────────
#define UART_TX     17
#define UART_RX     16
#define ENC_A       34
#define ENC_B       35
#define ENC_Z        4       // Dichiarato ma non utilizzato
#define PWM_OUT     15
#define GPIO_OUT_1  26       // EN (Driver Motore)
#define GPIO_OUT_2  25       // DIR (Driver Motore)
#define GPIO_IRQ_1  32       // Limit Switch 1 (Home)
#define GPIO_IRQ_2  33       // Limit Switch 2 (End)
#define GPIO_OUT_3  27       // Ausiliario
#define GPIO_OUT_4  14       // Ausiliario
#define GPIO_IN_1   39       // Ausiliario
#define GPIO_IN_2   13       // Ausiliario
#define I2C_SDA     21
#define I2C_SCL     22
#define PIN_CS      5        // SPI CS per EEPROM

// ── COSTANTI EEPROM & SENSORI ────────────────────────────────────
#define EEPROM_WREN   0x06
#define EEPROM_WRITE  0x02
#define EEPROM_READ   0x03
#define SDP_ADDR      0x25
#define SFM_ADDR      0x40

const float SDP_SCALE_FACTOR = 60.0;
const float SFM_SCALE_FACTOR = 120.0;
const uint16_t SFM_OFFSET = 32768;

// ── UUID BLUETOOTH (UART Custom) ─────────────────────────────────
#define SERVICE_UUID           "6E400001-B5A3-F393-E0A9-E50E24DCCA9E"
#define CHARACTERISTIC_UUID_RX "6E400002-B5A3-F393-E0A9-E50E24DCCA9E"
#define CHARACTERISTIC_UUID_TX "6E400003-B5A3-F393-E0A9-E50E24DCCA9E"

// ── STRUTTURA DATI MEMORIA (EEPROM) ──────────────────────────────
struct Config {
    float Kp[3]; // 0: SDP, 1: SFM, 2: ENC
    float Ki[3];
    float Kd[3];
    uint8_t active_sensor;
    float firmware_version;
    float syringe_area;
    float syringe_length;
    float fluid_resistance;
} sys_config;

// ── VARIABILI DI STATO GLOBALI ───────────────────────────────────
ESP32Encoder encoder;
hw_timer_t *timer = NULL;
NimBLECharacteristic* pTxCharacteristic;

volatile bool tick_200hz = false;
volatile bool emergency_stop = false;
long max_ticks = 10000;

enum OpMode { MODE_IDLE, MODE_CONST, MODE_SINE, MODE_CALIB, MODE_DEBUG };
OpMode current_mode = MODE_IDLE;

float current_flow = 0.0;
float current_pressure = 0.0;
float target_flow_setpoint = 0.0;
int manual_pwm_input = 0;

// Variabili PID & Calibrazione
float integral_err = 0.0, prev_err = 0.0;
uint32_t telemetry_timer = 0;
float cal_sum_pressure = 0.0;
float cal_sum_flow = 0.0;
uint32_t cal_samples = 0;

// ── INTERRUPT ────────────────────────────────────────────────────
void IRAM_ATTR onTimer() {
    tick_200hz = true;
}

void IRAM_ATTR limitSwitchISR() {
    emergency_stop = true;
    ledcWrite(PWM_OUT, 0);   // Modificato per Core 3.x
    digitalWrite(GPIO_OUT_1, LOW); // Disabilita driver H-Bridge
}

// ── DRIVER SPI EEPROM (25AA256) ──────────────────────────────────
void eeprom_write_enable() {
    digitalWrite(PIN_CS, LOW);
    SPI.transfer(EEPROM_WREN);
    digitalWrite(PIN_CS, HIGH);
}

void saveConfigToEEPROM() {
    eeprom_write_enable();
    delay(5);
    digitalWrite(PIN_CS, LOW);
    SPI.transfer(EEPROM_WRITE);
    SPI.transfer(0x00); 
    SPI.transfer(0x00); 
    
    uint8_t* ptr = (uint8_t*)&sys_config;
    for (size_t i = 0; i < sizeof(Config); i++) {
        SPI.transfer(ptr[i]);
    }
    digitalWrite(PIN_CS, HIGH);
    delay(10);
}

void loadConfigFromEEPROM() {
    digitalWrite(PIN_CS, LOW);
    SPI.transfer(EEPROM_READ);
    SPI.transfer(0x00);
    SPI.transfer(0x00);
    
    uint8_t* ptr = (uint8_t*)&sys_config;
    for (size_t i = 0; i < sizeof(Config); i++) {
        ptr[i] = SPI.transfer(0x00);
    }
    digitalWrite(PIN_CS, HIGH);
    
    if (isnan(sys_config.firmware_version) || sys_config.firmware_version <= 0) {
        sys_config.firmware_version = 1.0;
        sys_config.active_sensor = 2; // Default Encoder
        sys_config.syringe_area = 5.0;
        sys_config.syringe_length = 0.1;
        sys_config.fluid_resistance = 1.0;
        for(int i=0; i<3; i++) { sys_config.Kp[i]=1.0; sys_config.Ki[i]=0.1; sys_config.Kd[i]=0.01; }
        saveConfigToEEPROM();
    }
}

// ── DRIVER I2C SENSIRION (BARE-METAL) ────────────────────────────
void initSensorsRaw() {
    Wire.begin(I2C_SDA, I2C_SCL);
    Wire.setClock(400000); 

    // Start SDP810
    Wire.beginTransmission(SDP_ADDR);
    Wire.write(0x36); Wire.write(0x15);
    Wire.endTransmission();

    // Start SFM3300
    Wire.beginTransmission(SFM_ADDR);
    Wire.write(0x10); Wire.write(0x00);
    Wire.endTransmission();
    delay(100);
}

void readSDP_Raw() {
    Wire.requestFrom((uint16_t)SDP_ADDR, (uint8_t)3, (uint8_t)true);
    if (Wire.available() >= 2) {
        int16_t raw_pres = (Wire.read() << 8) | Wire.read();
        Wire.read();
        current_pressure = (float)raw_pres / SDP_SCALE_FACTOR;
    }
}

void readSFM_Raw() {
    Wire.requestFrom((uint16_t)SFM_ADDR, (uint8_t)3, (uint8_t)true);
    if (Wire.available() >= 2) {
        uint16_t raw_flow = (Wire.read() << 8) | Wire.read();
        Wire.read();
        current_flow = ((float)raw_flow - SFM_OFFSET) / SFM_SCALE_FACTOR;
    }
}

// ── PARSER UNIFICATO (BLE, USB, UART) ────────────────────────────
void processCommand(String cmd) {
    cmd.trim();
    if (cmd.length() == 0) return;
    
    Serial.println("[CMD RX] " + cmd);
    Serial2.println("[CMD RX] " + cmd);

    if (cmd.startsWith("SET_MODE:")) {
        current_mode = (OpMode)cmd.substring(9).toInt();
        integral_err = 0; prev_err = 0;
        cal_sum_pressure = 0; cal_sum_flow = 0; cal_samples = 0;
    } 
    else if (cmd.startsWith("SET_FLOW:")) {
        target_flow_setpoint = cmd.substring(9).toFloat();
    } 
    else if (cmd.startsWith("SET_PWM:")) {
        manual_pwm_input = cmd.substring(8).toInt();
    }
    else if (cmd.startsWith("SET_SENS:")) {
        sys_config.active_sensor = cmd.substring(9).toInt();
    }
    else if (cmd.startsWith("CONFIG:")) {
        int idx = cmd.indexOf(':') + 1;
        int comma1 = cmd.indexOf(',', idx);
        int comma2 = cmd.indexOf(',', comma1 + 1);
        int comma3 = cmd.indexOf(',', comma2 + 1);
        int comma4 = cmd.indexOf(',', comma3 + 1);
        int comma5 = cmd.indexOf(',', comma4 + 1);
        int comma6 = cmd.indexOf(',', comma5 + 1);
        
        int s_idx = cmd.substring(idx, comma1).toInt();
        sys_config.Kp[s_idx] = cmd.substring(comma1+1, comma2).toFloat();
        sys_config.Ki[s_idx] = cmd.substring(comma2+1, comma3).toFloat();
        sys_config.Kd[s_idx] = cmd.substring(comma3+1, comma4).toFloat();
        sys_config.syringe_area = cmd.substring(comma4+1, comma5).toFloat();
        sys_config.syringe_length = cmd.substring(comma5+1, comma6).toFloat();
        sys_config.fluid_resistance = cmd.substring(comma6+1).toFloat();
        saveConfigToEEPROM();
        
        Serial.println("[CONFIG] EEPROM Aggiornata");
        Serial2.println("[CONFIG] EEPROM Aggiornata");
    }
    else if (cmd == "RESET_ERR") {
        emergency_stop = false;
        digitalWrite(GPIO_OUT_1, HIGH);
    }
}
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

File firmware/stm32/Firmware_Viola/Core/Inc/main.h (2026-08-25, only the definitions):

#define FAULT_ESCON_Pin GPIO_PIN_14
#define FAULT_ESCON_GPIO_Port GPIOC
#define ENC_A_Pin GPIO_PIN_0
#define ENC_A_GPIO_Port GPIOA
#define ENC_B_Pin GPIO_PIN_1
#define ENC_B_GPIO_Port GPIOA
#define EN_ESCON_Pin GPIO_PIN_0
#define EN_ESCON_GPIO_Port GPIOB
#define DIR_ESCON_Pin GPIO_PIN_1
#define DIR_ESCON_GPIO_Port GPIOB
#define PWM_ESCON_Pin GPIO_PIN_8
#define PWM_ESCON_GPIO_Port GPIOA
#define HC_05_TX_Pin GPIO_PIN_9
#define HC_05_TX_GPIO_Port GPIOA
#define HC_05_RX_Pin GPIO_PIN_10
#define HC_05_RX_GPIO_Port GPIOA
#define ENC_Z_Pin GPIO_PIN_12
#define ENC_Z_GPIO_Port GPIOA
#define LED_GREEN_Pin GPIO_PIN_5
#define LED_GREEN_GPIO_Port GPIOA
#define SPI_SCK_Pin GPIO_PIN_3
#define SPI_SCK_GPIO_Port GPIOB
#define SPI_MISO_Pin GPIO_PIN_4
#define SPI_MISO_GPIO_Port GPIOB
#define SPI_MOSI_Pin GPIO_PIN_5
#define SPI_MOSI_GPIO_Port GPIOB
#define SCL_Pin GPIO_PIN_6
#define SCL_GPIO_Port GPIOB
#define SDA_Pin GPIO_PIN_7
#define SDA_GPIO_Port GPIOB

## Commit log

2026-04-01 added 3D and PCB folders,created default pcb project on kicad
    [motherboard.kicad_pcb, motherboard.kicad_sch]
2026-04-01 schematic template added
    [connectors.kicad_sch, motherboard.kicad_sch, power.kicad_sch]
2026-04-08 added kicad libraries for power
2026-04-08 started power schematic of pcb
    [motherboard.kicad_sch, power.kicad_sch]
2026-04-10 updated sch power
    [ESCON50_5_sch.kicad_sch, motherboard.kicad_sch, power.kicad_sch]
2026-04-15 aggiunto driver escon in libreria e nel progetto schematico
    [ESCON50_5_sch.kicad_sch, mcu_eeprom.kicad_sch, motherboard.kicad_sch]
2026-04-15 test kicad collab
    [connectors.kicad_sch]
2026-04-15 layout connettori + note
    [connectors.kicad_sch]
2026-04-15 added hierrcical labels mcu, added filters for escon + labels
    [ESCON50_5_sch.kicad_sch, mcu_eeprom.kicad_sch]
2026-04-15 match label
    [ESCON50_5_sch.kicad_sch, bckup.kicad_pcb, bckup.kicad_sch]
2026-04-15 reverse current protection on ESCON+others
    [ESCON50_5_sch.kicad_sch, connectors.kicad_sch, mcu_eeprom.kicad_sch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]
2026-04-17 collegamenti tra blocchi schematico, sistemati connettori,finita la parte di shunt monitor per back EMF escon, aggiunti status LED, aggiunti bulk cap su alimentazione+altre modifiche
    [ESCON50_5_sch.kicad_sch, connectors.kicad_sch, mcu_eeprom.kicad_sch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]
2026-04-22 schematics need only sizing
    [ESCON50_5_sch.kicad_sch, connectors.kicad_sch, mcu_eeprom.kicad_sch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]
2026-04-22 sizing schematics done
    [ESCON50_5_sch.kicad_sch, connectors.kicad_sch, mcu_eeprom.kicad_sch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]
2026-04-22 assegnazione footprint connettori
    [connectors.kicad_sch]
2026-04-22 aggiunta footprint escon
2026-04-22 added footprint for all components
2026-04-22 added last footprint on sch
    [ESCON50_5_sch.kicad_sch, mcu_eeprom.kicad_sch, motherboard.kicad_pcb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]
2026-04-24 pcb layout
    [ESCON50_5_sch.kicad_sch, connectors.kicad_sch, mcu_eeprom.kicad_sch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]
2026-04-25 pcb layout : collegamento piste + vie + cambio connettori
    [connectors.kicad_sch, motherboard.kicad_pcb]
2026-04-29 resolved pcb errors from drc, generated test output files
    [bckup.kicad_pcb, bckup.kicad_sch, bom.csv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]
2026-05-03 Finito Calibratore
2026-07-16 motherboard PCB rev2
    [ESCON50_5_sch.kicad_sch, Sensirion_Mass_Flow_Meters_Software_SFM-CAP_STEP-file.step, adapter.step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]
2026-08-25 updated the project tree, updated README
    [ESCON50_5_sch.kicad_sch, Sensirion_Mass_Flow_Meters_Software_SFM-CAP_STEP-file.step, adapter.step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]

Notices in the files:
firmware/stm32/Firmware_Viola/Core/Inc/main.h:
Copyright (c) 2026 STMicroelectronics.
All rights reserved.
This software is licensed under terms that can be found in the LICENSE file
